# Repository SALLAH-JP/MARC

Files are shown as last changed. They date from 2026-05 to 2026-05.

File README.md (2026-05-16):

<div align="center">

MARC - Robot guide autonome

# 🤖 MARC

### *Mascareignes Assistant and Robot Compagnon*

**Robot mobile autonome, guide vocal du laboratoire de robotique de l'Université des Mascareignes.**








[**🎥 Voir la démo**](#-démonstration) · [**🚀 Installation**](#-installation) · [**📖 Documentation**](#-documentation)

</div>

---

## 📺 Démonstration

> 🎬 **[▶️ Cliquez ici pour voir MARC en action sur YouTube](https://youtu.be/REMPLACER_PAR_LIEN_YOUTUBE)**

MARC Demo (https://youtu.be/REMPLACER_PAR_LIEN_YOUTUBE)

*MARC navigue entre les stations du laboratoire, présente les robots et interagit vocalement.*

---

## 📋 Sommaire

- [À propos](#-à-propos)
- [Aperçu](#-aperçu)
- [Architecture](#%EF%B8%8F-architecture)
- [Matériel](#-matériel)
- [Structure du dépôt](#-structure-du-dépôt)
- [Installation](#-installation)
- [Utilisation](#-utilisation)
- [Architecture logicielle](#-architecture-logicielle)
- [Documentation](#-documentation)
- [Auteur](#-auteur)

---

## 🎯 À propos

MARC est un **projet de fin d'études** développé en 3ème année d'Informatique Appliquée à l'**Université des Mascareignes** (Maurice), en partenariat avec l'**Université de Limoges**.

L'objectif : créer un robot guide capable de **se déplacer de manière autonome** entre 7 stations du laboratoire de robotique, de **dialoguer en langage naturel** grâce à un Grand Modèle de Langage, et d'**exprimer des émotions** via une matrice LED. Le tout supervisé depuis une interface web temps réel.

Le robot est entièrement conçu à partir de zéro : **modélisation 3D sur Onshape**, **impression 3D**, **électronique custom**, **firmware embarqué** et **stack logiciel complet**.

---

## ✨ Aperçu

- 🧭 **Navigation autonome** par suivi de ligne (3 capteurs IR) entre 7 stations
- 🎙️ **Pipeline vocal complet** : Speech-to-Text → LLM cloud (Mistral via Ollama) → Text-to-Speech
- 🧠 **Sortie JSON structurée** : le LLM génère directement des commandes exécutables
- 🌐 **Interface web HTTPS temps réel** : parcours SVG, journal d'événements, Push-To-Talk, mises à jour SSE
- 👀 **Matrice LED RGB 64×32** avec 6 expressions GIF (neutre, clignement, suspicieux, disparition, larme, amour)
- ⚖️ **Tentative auto-équilibrante PID** documentée et analysée *(mode finalement abandonné pour la navigation, voir le rapport)*

<div align="center">
Matrice LED RGB de MARC
<br/>
<i>La matrice LED RGB 64×32 pendant les tests d'animation</i>
</div>

---

## 🏗️ Architecture

Le système est distribué en trois couches :

```
┌─────────────────────────────────────────────┐
│  Couche matérielle                          │
│  Arduino Mega 2560 — 16 MHz, PID 100 Hz     │
│  Moteurs NEMA 23 · TB6600 · IR · BNO085     │
└──────────────────┬──────────────────────────┘
                   │ UART 115 200 bauds
                   │ (/dev/ttyACM0)
┌──────────────────┴──────────────────────────┐
│  Couche applicative                         │
│  Raspberry Pi 4 Model B — 1 Go RAM          │
│  Flask HTTPS + SSE · pipeline vocal · LED   │
└──────────────────┬──────────────────────────┘
                   │ HTTPS — API Ollama
┌──────────────────┴──────────────────────────┐
│  Intelligence distante                      │
│  Mistral Large via Ollama Cloud             │
│  Sortie JSON structurée                     │
└─────────────────────────────────────────────┘
```

---

## 🔧 Matériel

<div align="center">
Plateforme matérielle de MARC
<br/>
<i>Vue rapprochée du châssis : moteurs NEMA 23, drivers TB6600 et électronique de commande</i>
</div>

| Composant | Référence |
| --- | --- |
| Microcontrôleur | Arduino Mega 2560 |
| Ordinateur de bord | Raspberry Pi 4 Model B (1 Go RAM) |
| Moteurs | Pas-à-pas NEMA 23 ×2 |
| Drivers moteurs | TB6600 ×2 |
| Centrale inertielle | BNO085 (SPI, CS pin 47) |
| Capteurs ligne | 3 capteurs IR — pins 49 (G), 40 (C), 48 (D) |
| Affichage | Matrice LED RGB 64×32 (HUB75) |
| Télécommande | Récepteur IR (pin 46) — réglage PID, manuel |

> 💡 La modélisation 3D complète a été réalisée sur **Onshape** et le robot a été imprimé en 3D au laboratoire de l'UDM.

---

## 🧱 Conception 3D

L'intégralité de la mécanique de MARC a été **modélisée sur Onshape** puis **imprimée en 3D** au laboratoire de l'UDM. Le robot se décompose en **3 sous-ensembles** : la coque externe esthétique, la structure interne porteuse, et la tête (matrice LED).

<div align="center">
Modélisation Onshape de MARC
<br/>
<i>Modèle 3D complet de MARC sur Onshape</i>
</div>

### 🔗 Visualisation interactive

👉 **[Voir le modèle 3D complet sur Onshape](https://cad.onshape.com/documents/bc8d4e2fc1fa99c54b0ae445/w/f22cc56c4e97ab29b572a8dc/e/e2a230c46f8ff9770799be93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)**

### 📦 Fichiers 3D disponibles

Tous les fichiers source sont dans [`hardware/3d-models/`](assets/3d-models/), au format **STL** (impression directe) et **STEP** (édition CAO).

> 💡 Astuce : cliquez sur n'importe quel fichier `.stl` directement sur GitHub pour le **visualiser en 3D** dans votre navigateur.

#### 🏛️ Coque externe

Habillage esthétique du robot, imprimé en plusieurs morceaux pour respecter les contraintes du plateau d'impression.

| Pièce | STL | STEP |
|---|-----|---|
| Colonne V3 | [STL](assets/3d-models/ColonneV3.stl) | [STEP](assets/3d-models/ColonneV3.step) |
| Corps Bas — Avant | [STL](assets/3d-models/CorpsBasAvant.stl) | [STEP](assets/3d-models/CorpsBasAvant.step) |
| Corps Bas — Arrière | [STL](assets/3d-models/CorpsBasArriere.stl) | [STEP](assets/3d-models/CorpsBasArriere.step) |
| Corps Haut — Avant | [STL](assets/3d-models/CorpsHautAvant.stl) | [STEP](assets/3d-models/CorpsHautAvant.step) |
| Corps Haut — Arrière | [STL](assets/3d-models/CorpsHautArriere.stl) | [STEP](assets/3d-models/CorpsHautArriere.step) |
| Étage 0 (base) | [STL](assets/3d-models/Etage0.stl) | [STEP](assets/3d-models/Etage0.step) |
| Porte d'accès | [STL](assets/3d-models/Porte.stl) | [STEP](assets/3d-models/Porte.step) |
| Support capteurs IR | [STL](assets/3d-models/SupportTrackingSensor.stl) | [STEP](assets/3d-models/SupportTrackingSensor.step) |

#### 🦴 Structure interne

Squelette porteur qui supporte l'électronique, les moteurs et les batteries.

| Pièce | STL | STEP |
|---|-----|---|
| Colonne V1 | [STL](assets/3d-models/ColonneV1.stl) | [STEP](assets/3d-models/ColonneV1.step) |
| Coque interne | [STL](assets/3d-models/Coque.stl) | [STEP](assets/3d-models/Coque.step) |
| Étage 1 | [STL](assets/3d-models/Etage1.stl) | [STEP](assets/3d-models/Etage1.step) |
| Étage 2 | [STL](assets/3d-models/Etage2.stl) | [STEP](assets/3d-models/Etage2.step) |
| Étage 3 | [STL](assets/3d-models/Etage3.stl) | [STEP](assets/3d-models/Etage3.step) |
| Bague de réduction | [STL](assets/3d-models/BagueDeReduction.stl) | [STEP](assets/3d-models/BagueDeReduction.step) |
| Roue | [STL](assets/3d-models/Roue.stl) | [STEP](assets/3d-models/Roue.step) |
| Part 8 | [STL](assets/3d-models/Part8.stl) | [STEP](assets/3d-models/Part8.step) |

#### 🤖 Tête

Module supérieur portant la matrice LED 64×32 (le « visage » de MARC).

| Pièce | STL | STEP |
|---|-----|---|
| Tête — partie basse | [STL](assets/3d-models/TeteBas.stl) | [STEP](assets/3d-models/TeteBas.step) |
| Tête — partie haute | [STL](assets/3d-models/Tete-Haut.stl) | [STEP](assets/3d-models/TeteHaut.step) |
| Cadre matrice LED | [STL](assets/3d-models/tete/Matrice-Led.stl) | [STEP](assets/3d-models/MatriceLed.step) |

---

## 📁 Structure du dépôt

```
.
├── ControlMoteur/                 # Code embarqué Arduino Mega
│   ├── ControlMoteur.ino          # Boucle principale : PID, suivi de ligne, série
│   ├── header.h                   # Définitions broches, constantes, objets PID
│   └── fonctions.ino              # Fonctions auxiliaires (setMotors, lineTracking…)
│
├── Local-Voice/                   # Pipeline vocal Python (fork m15-ai/Local-Voice)
│   ├── voiceAssistant.py          # STT (Google) → LLM (Ollama cloud) → TTS (Edge)
│   ├── modelfile.txt              # Prompt système + base de connaissances
│   ├── requirements.txt
│   └── piper/                     # (optionnel) binaire Piper + voix offline
│
├── matrixLed/                     # Pilotage de la matrice LED RGB 64×32
│   ├── eye_manager.py             # Gestion thread-safe des animations + clignement
│   ├── gif_viewer.py              # Lecteur GIF simple (test standalone)
│   ├── SplitEyes.py               # Génération des GIFs depuis une vidéo source
│   ├── style1/                    # Set d'expressions style 1 (6 GIF)
│   └── style2/                    # Set d'expressions style 2 (6 GIF)
│
├── web/                           # Serveur Flask + interface web
│   ├── server.py                  # Flask HTTPS + SSE + worker série
│   ├── index.html                 # Application monopage HTML/CSS/JS
│   ├── style.css                  # Styles (parcours SVG, journal, Push-To-Talk)
│   ├── cert.pem / key.pem         # Certificat SSL auto-signé (à générer)
│   └── ...
│
├── docs/
│   ├── images/                    # Photos et captures du projet
│   └── Rapport_PFE_MARC.pdf       # Rapport complet du projet
│
└── .gitignore
```

---

## 🚀 Installation

### Prérequis

- Raspberry Pi 4 (Raspberry Pi OS 64 bits recommandé)
- Arduino Mega 2560 + IDE Arduino
- Python 3.9 ou supérieur
- Compte [Ollama](https://ollama.com) avec accès à l'API cloud (clé API)
- Réseau Wi-Fi local
- `ffmpeg`, `mpg123`, `sox`, `alsa-utils` installés sur le Pi

### Côté Arduino

1. Ouvrir `ControlMoteur/ControlMoteur.ino` dans l'IDE Arduino.
2. Installer via le gestionnaire de bibliothèques :
   - [`FastAccelStepper`](https://github.com/gin66/FastAccelStepper)
   - [`IRremote`](https://github.com/Arduino-IRremote/Arduino-IRremote)
   - [`SparkFun BNO08x Arduino Library`](https://github.com/sparkfun/SparkFun_BNO08x_Arduino_Library)
   - `PID_v1` (Brett Beauregard)
3. Vérifier les broches dans `header.h` (STEP/DIR/ENABLE moteurs, capteurs IR, BNO085, télécommande IR).
4. Compiler et téléverser sur l'Arduino Mega.

### Côté Raspberry Pi

```bash
# Cloner le dépôt
git clone https://github.com/SALLAH-JP/MARC.git
cd MARC

# Environnement Python
python3 -m venv env
source env/bin/activate
pip install -r Local-Voice/requirements.txt
pip install flask pyserial speechrecognition edge-tts pydub pillow

# Bibliothèque matrice LED (compilation native, requiert sudo plus tard)
git clone https://github.com/hzeller/rpi-rgb-led-matrix
cd rpi-rgb-led-matrix && make build-python PYTHON=$(which python3) && cd ..

# Dépendances système
sudo apt install ffmpeg mpg123 sox alsa-utils portaudio19-dev

# Certificat SSL auto-signé (HTTPS obligatoire pour le micro côté navigateur)
cd web
openssl req -x509 -newkey rsa:4096 -keyout key.pem -out cert.pem -days 365 -nodes
cd ..

# Variables d'environnement Ollama
export OLLAMA_API_KEY="<votre_clé>"
export OLLAMA_HOST="https://ollama.com"
```

### Lancement

```bash
# Terminal 1 — serveur web (HTTPS, port 5000) + matrice LED
cd web
sudo -E python3 server.py

# Terminal 2 — assistant vocal (wake word + commande)
cd Local-Voice
python3 voiceAssistant.py
```

L'interface web est accessible sur `https://<ip-du-pi>:5000` depuis n'importe quel appareil du réseau local. Le navigateur affichera un avertissement de sécurité dû au certificat auto-signé — c'est normal sur un réseau local, accepter l'exception.

> ⚠️ **Note** : `sudo` est nécessaire pour `server.py` car la bibliothèque `rpi-rgb-led-matrix` requiert un accès direct aux GPIO. Le drapeau `-E` préserve les variables d'environnement.

---

## 🎮 Utilisation

### Commande vocale

1. Dire le mot de réveil : *« Salut Marc »*.
2. Énoncer la commande, par exemple :
   - *« Va voir Pepper »* → navigation autonome jusqu'à la station Pepper
   - *« Présente-moi NAO »* → MARC s'y rend et donne une présentation
   - *« Reviens à la base »* → retour station 0
   - *« Change tes yeux »* → bascule entre style 1 et 2
3. MARC interprète la requête, confirme oralement et exécute.

### Interface web

- Cliquer sur une station du parcours SVG pour y envoyer le robot
- Activer ou désactiver le mode guide
- Push-To-Talk pour enregistrer une commande vocale depuis le navigateur
- Suivre le journal des événements en temps réel (SSE — pas de rechargement)

### Stations disponibles

| ID web | Numéro physique | Équipement |
| --- | --- | --- |
| base | 0 | Point de départ |
| nao | 1 | Robot humanoïde NAO |
| vector | 2 | Robot mobile Vector |
| pepper | 3 | Robot humanoïde Pepper |
| imp3d | 4 | Imprimante 3D Zortrax |
| baxter | 5 | Robot industriel Baxter |
| bras | 6 | Bras Franka Panda |

---

## 🧩 Architecture logicielle

**`ControlMoteur/`** — boucle Arduino à 200–500 Hz qui lit l'IMU, interprète les trames série venant du Pi (`C:move:turn` et `M:0/1`), exécute soit le suivi de ligne soit la télécommande IR, calcule les deux PID (équilibre + vitesse) et envoie les pas aux moteurs via FastAccelStepper. Quand une nouvelle station est détectée, l'Arduino renvoie `S:N` au Pi.

**`web/server.py`** — serveur Flask HTTPS qui héberge l'interface, expose les routes `/command`, `/vocal_command`, `/transcribe`, `/status`, `/line_following`, et un flux SSE `/events` pour les mises à jour temps réel vers le navigateur. Un thread daemon tourne en parallèle pour la communication série.

**`Local-Voice/voiceAssistant.py`** — pipeline vocal indépendant : écoute permanente du wake word via SpeechRecognition (Google STT), interprétation par Mistral Large via l'API Ollama cloud avec sortie JSON contrainte, synthèse vocale française avec `edge-tts` (voix `fr-FR-HenriNeural`), envoi de la commande au serveur Flask via HTTPS POST.

**`matrixLed/eye_manager.py`** — gestionnaire thread-safe de la matrice LED, clignement aléatoire en arrière-plan (3 à 7 secondes), interruption immédiate pour jouer une animation à la demande, rechargement à chaud lors d'un changement de style.

---

## 📖 Documentation

Le rapport complet de Projet de Fin d'Études détaille :
- l'analyse des besoins
- les choix d'architecture
- l'analyse du conflit PID-équilibre vs suivi de ligne
- les tests d'une vingtaine de modèles LLM réalisés sur Raspberry Pi 4
- la modélisation 3D sur Onshape
- les résultats expérimentaux

📄 Disponible dans [`docs/Rapport_PFE_MARC.pdf`](docs/Rapport_PFE_MARC.pdf).

---

## 👤 Auteur

**SALLAH Assiongbon Théodore Jean-Paul**
Étudiant en 3ème année — Informatique Appliquée
🎓 Université des Mascareignes · Université de Limoges
📅 Année universitaire 2024 / 2025

**Encadrant pédagogique :** M. Khadimoullah Ramoth



---

## 🙏 Remerciements

Ce projet doit beaucoup à plusieurs contributions extérieures :

- Le projet [Local-Voice](https://github.com/m15-ai/Local-Voice) de M15.ai, dont l'architecture a inspiré le pipeline vocal
- La plateforme [Ollama](https://ollama.com) et le modèle Mistral Large
- La bibliothèque [FastAccelStepper](https://github.com/gin66/FastAccelStepper) de J. Kerschbaumer
- La bibliothèque [rpi-rgb-led-matrix](https://github.com/hzeller/rpi-rgb-led-matrix) de H. Zeller
- [edge-tts](https://github.com/rany2/edge-tts), [Flask](https://flask.palletsprojects.com), [SpeechRecognition](https://github.com/Uberi/speech_recognition)
- Les fournisseurs locaux Advanced Electronique et Transcom (Maurice)

---

## 📜 Licence

Ce projet est distribué sous licence **MIT** — voir le fichier [`LICENSE`](LICENSE).

Le code des bibliothèques tierces utilisées reste sous leurs licences respectives.

---

<div align="center">

*Si ce projet vous a plu, n'hésitez pas à laisser une ⭐ !*

</div>

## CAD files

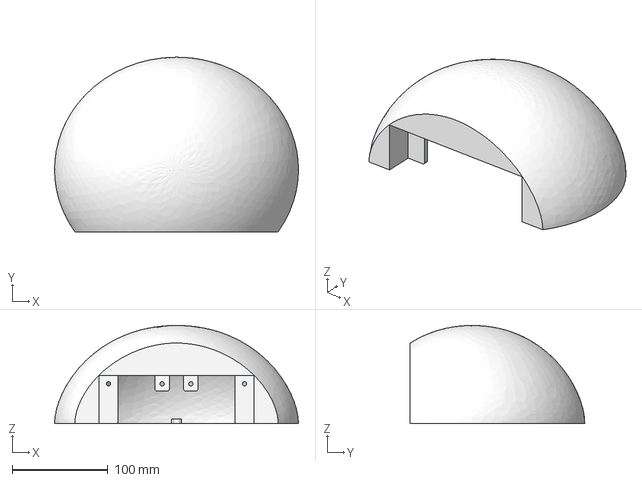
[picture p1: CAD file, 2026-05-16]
assets/3d-models/TeteHaut.step
255.0 x 182.5 x 102.5 mm

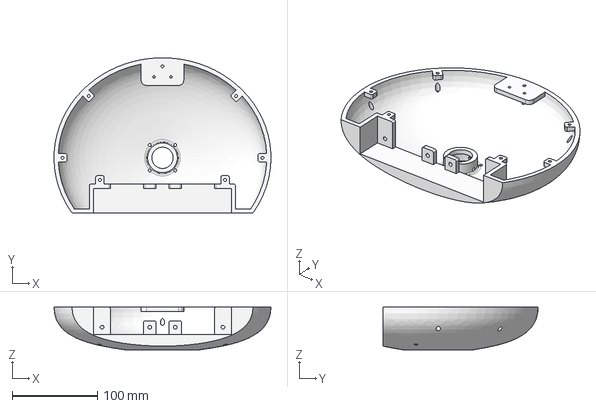
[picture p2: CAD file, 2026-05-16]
assets/3d-models/TeteBas.step
255.0 x 182.4 x 50.0 mm

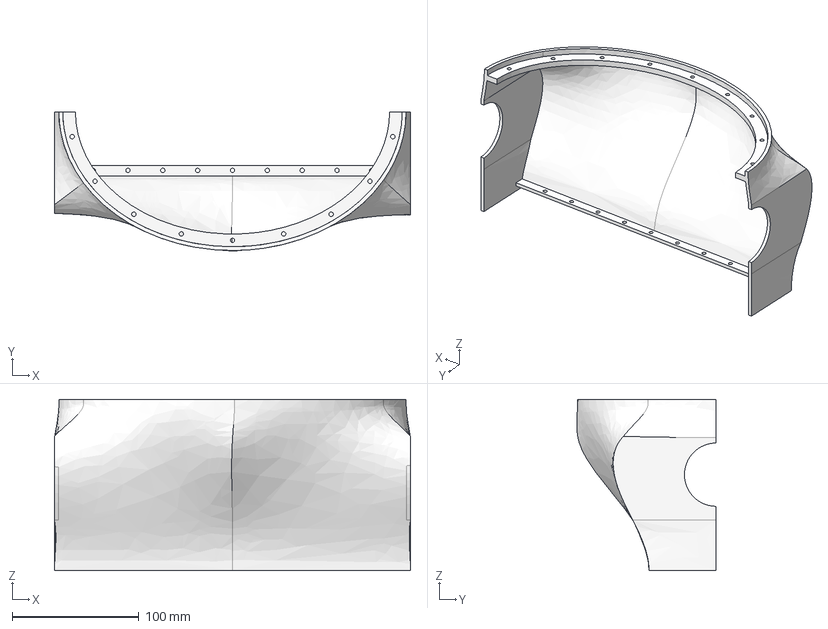
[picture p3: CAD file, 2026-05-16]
assets/3d-models/CorpsBasAvant.step
281.0 x 110.0 x 135.0 mm

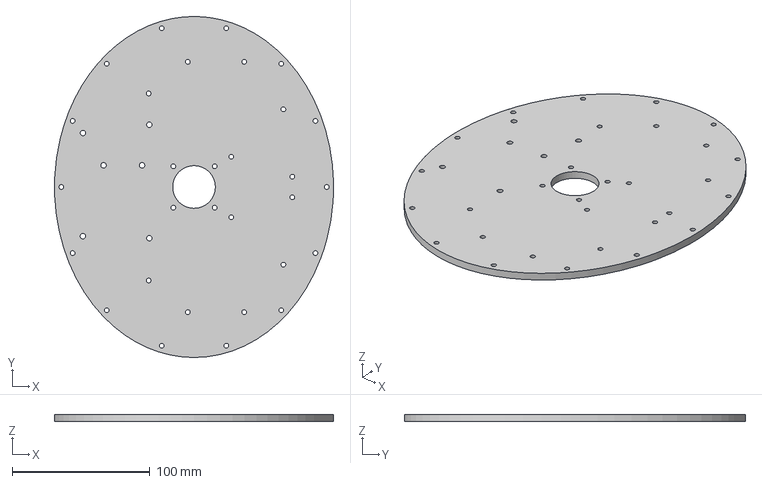
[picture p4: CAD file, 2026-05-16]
assets/3d-models/Etage2.step
203.0 x 248.0 x 5.00 mm

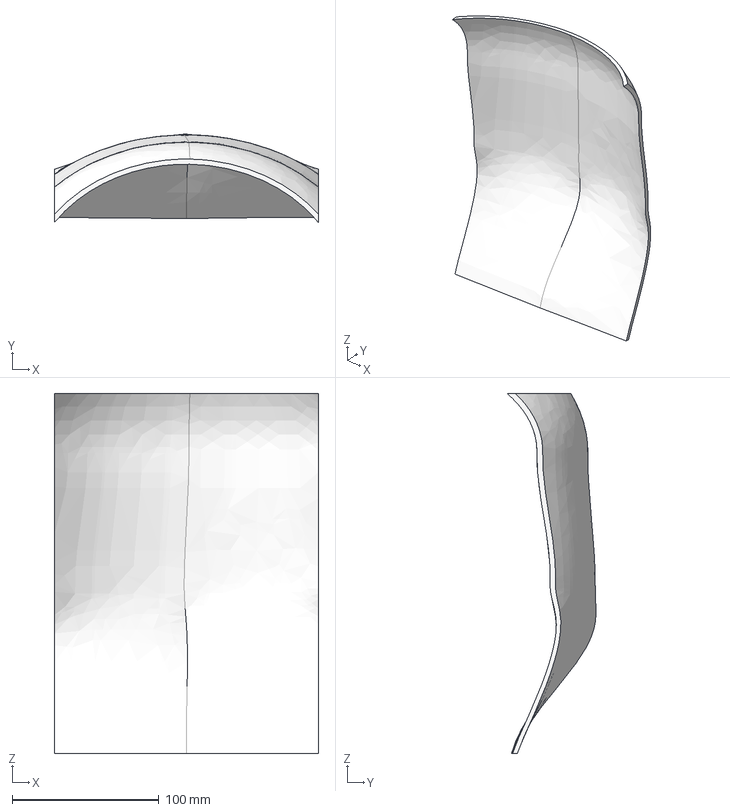
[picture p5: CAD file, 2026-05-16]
assets/3d-models/Porte.step
180.0 x 60.5 x 245.0 mm

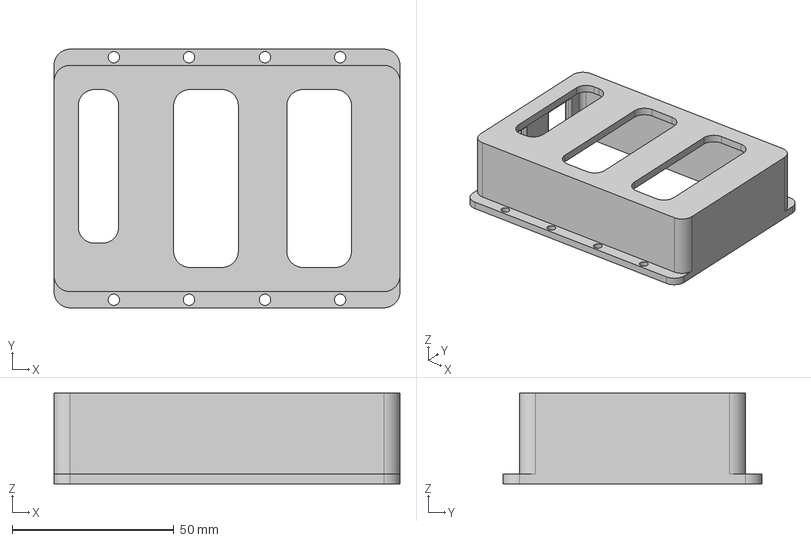
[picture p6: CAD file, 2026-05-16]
assets/3d-models/Coque.step
107.0 x 80.0 x 28.0 mm

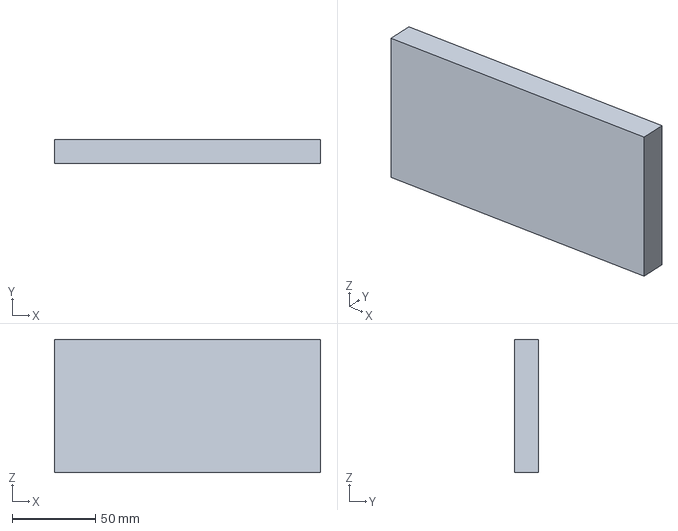
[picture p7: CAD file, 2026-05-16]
assets/3d-models/MatriceLed.step
160.0 x 14.5 x 80.0 mm

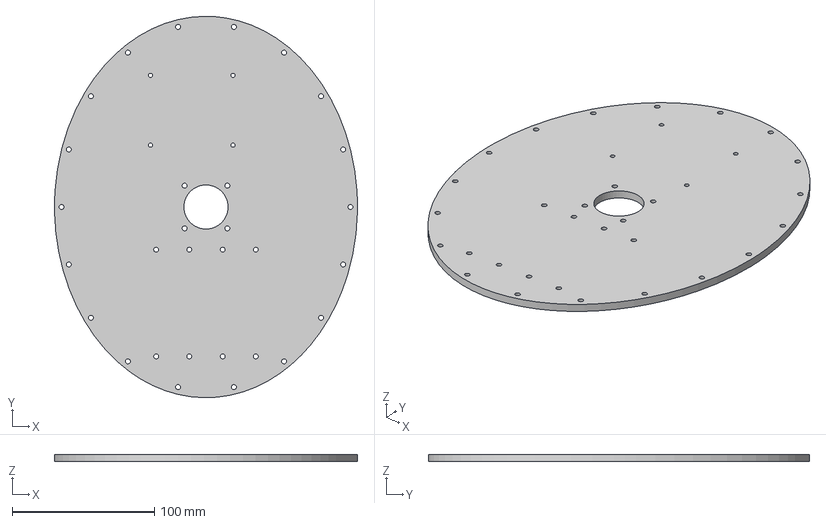
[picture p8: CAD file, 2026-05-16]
assets/3d-models/Etage3.step
212.9 x 268.0 x 5.00 mm

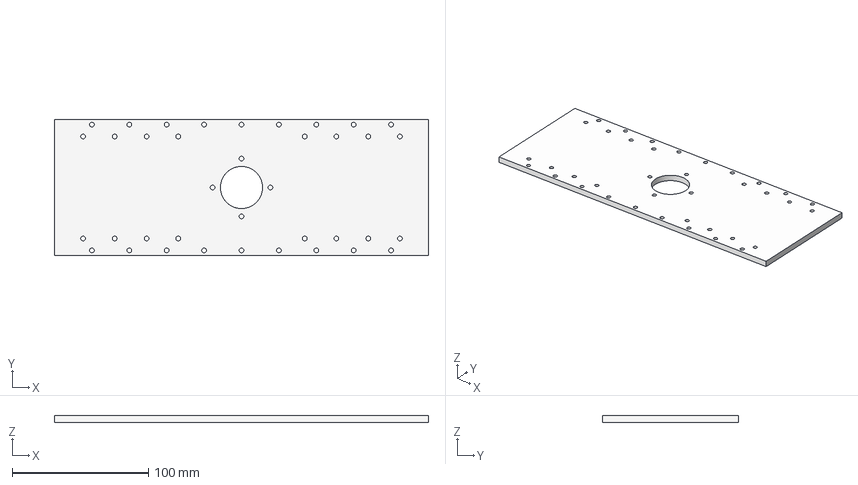
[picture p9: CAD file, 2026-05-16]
assets/3d-models/Etage0.step
275.0 x 100.0 x 5.00 mm

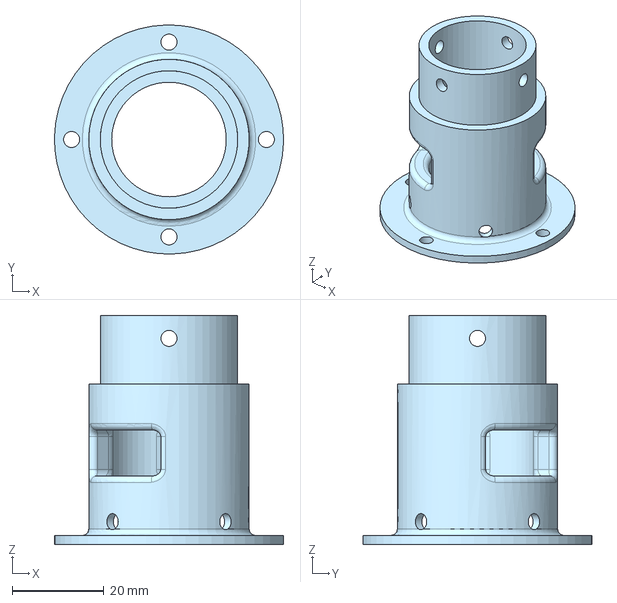
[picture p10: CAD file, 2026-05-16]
assets/3d-models/ColonneV3.step
50.0 x 50.0 x 50.0 mm

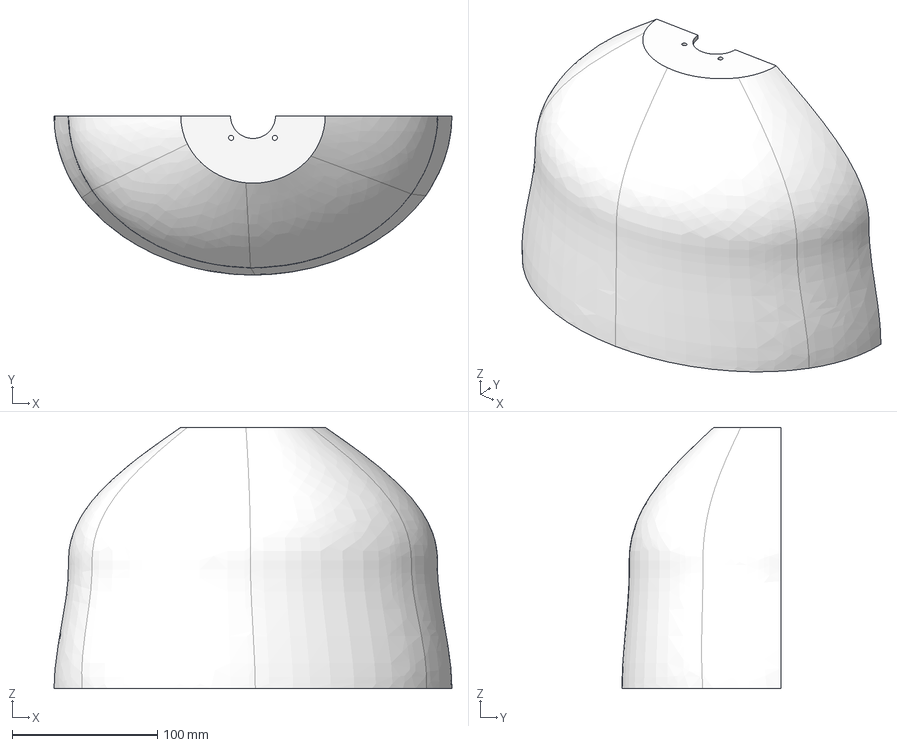
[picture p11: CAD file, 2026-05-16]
assets/3d-models/CorpsHautAvant.step
274.0 x 109.5 x 180.0 mm

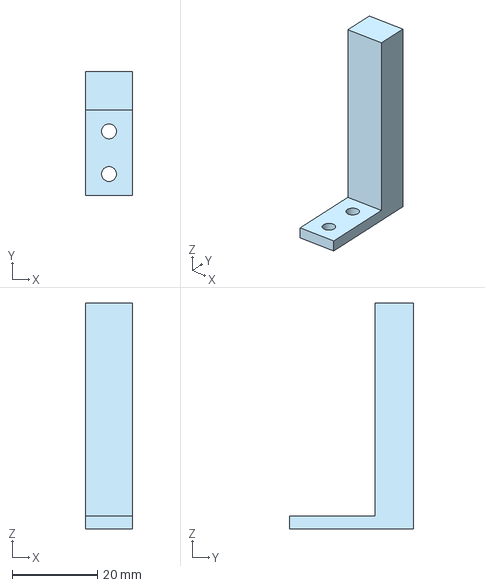
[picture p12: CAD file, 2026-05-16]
assets/3d-models/Part8.step
11.0 x 29.0 x 53.0 mm

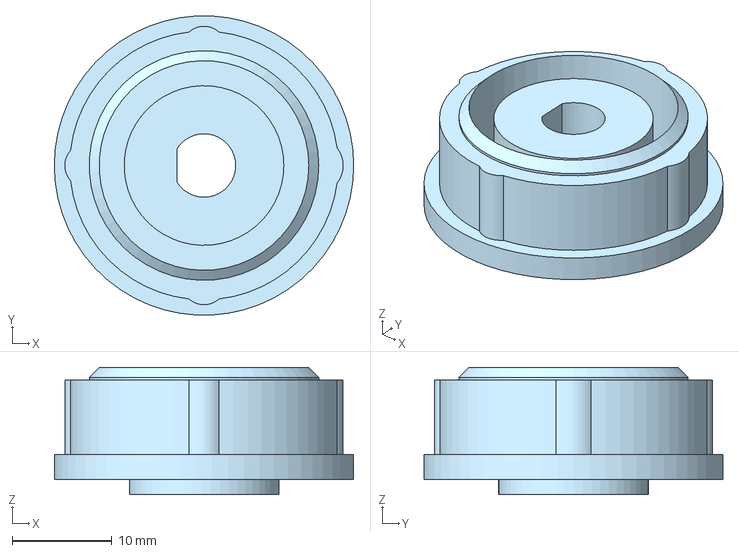
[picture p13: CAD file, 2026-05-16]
assets/3d-models/BagueDeReduction.step
30.0 x 30.0 x 12.8 mm

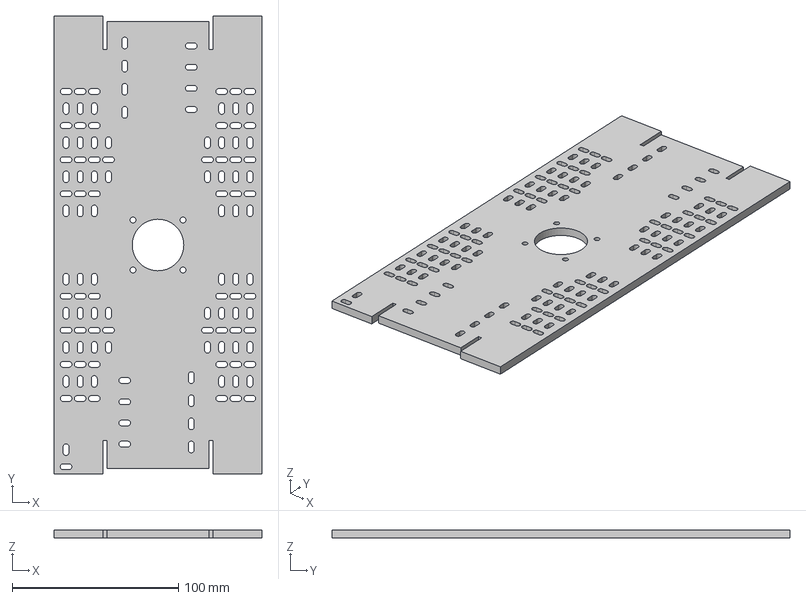
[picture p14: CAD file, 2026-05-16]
assets/3d-models/Etage1.step
125.0 x 275.0 x 5.00 mm

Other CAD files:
assets/3d-models/SupportTrackingSensor.step
assets/3d-models/CorpsBasArriere.step
assets/3d-models/CorpsHautArriere.step
assets/3d-models/Roue.step
assets/3d-models/BagueDeReduction.stl
assets/3d-models/ColonneV1.step
assets/3d-models/Coque.stl
assets/3d-models/CorpsBasArriere.stl
assets/3d-models/CorpsBasAvant.stl
assets/3d-models/CorpsHautArriere.stl
assets/3d-models/CorpsHautAvant.stl
assets/3d-models/Etage0.stl
assets/3d-models/Etage1.stl
assets/3d-models/Etage2.stl
assets/3d-models/Etage3.stl
assets/3d-models/MatriceLed.stl
assets/3d-models/Part8.stl
assets/3d-models/Porte.stl
assets/3d-models/Roue.stl
assets/3d-models/SupportTrackingSensor.stl
assets/3d-models/TeteBas.stl
assets/3d-models/TeteHaut.stl

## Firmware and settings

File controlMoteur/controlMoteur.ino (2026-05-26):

#include "header.h"


void setup() {
  Serial.begin(115200);

  Serial.println("Start Setup");


  //if (myIMU.begin() == false) {  // Setup without INT/RST control (Not Recommended)
  while (imu.beginSPI(BNO08X_CS, BNO08X_INT, BNO08X_RST) == false) {
    Serial.println("BNO08x not detected at default I2C address. Check your jumpers and the hookup guide. Freezing...");
    delay(100);
  }
  Serial.println("BNO08x found!");


  delay(100);
  setReports();
  Serial.println("Reading events");
  delay(100);

  // IR Receiver Setup and interrupt
  IrReceiver.begin(IR_PIN, ENABLE_LED_FEEDBACK);


  // Activer les moteurs
  engine.init();

  // Moteur droit
  motorR = engine.stepperConnectToPin(STEP_PIN_R);   // STEP droit
  if (motorR) {
    motorR->setDirectionPin(DIR_PIN_R);            // DIR droit
    motorR->setEnablePin(ENA_PIN_R, false);               // EN droit
    motorR->setAutoEnable(true);
    motorR->setAcceleration(3000);
  }

  // Moteur gauche
  motorL = engine.stepperConnectToPin(STEP_PIN_L);   // STEP gauche
  if (motorL) {
    motorL->setDirectionPin(DIR_PIN_L);            // DIR gauche
    motorL->setEnablePin(ENA_PIN_L, false);               // EN gauche
    motorL->setAutoEnable(true);
    motorL->setAcceleration(3000);
  }


  // Tracking Sensor Setup
  pinMode(LEFT_SENSOR_PIN, INPUT);
  pinMode(RIGHT_SENSOR_PIN, INPUT);
  pinMode(CENTER_SENSOR_PIN, INPUT);

  setupUltrasons();

  // PID
  pidA.SetSampleTime(10);
  pidA.SetOutputLimits(-5000, 5000);
  pidA.SetMode(AUTOMATIC);

  pidV.SetSampleTime(10);
  pidV.SetOutputLimits(-45, 45);
  pidV.SetMode(AUTOMATIC);


  Serial.println("Setup Completed !");
}


void loop() {

  if (imu.wasReset()) {
    Serial.print("sensor was reset ");
    setReports();
  }

  moveCmd = 0;
  turnCmd = 0;

  readSerialCommand();


  if (lineFollowingMode) {
    lineTracking();        // suit la ligne, ignore la télécommande
  } else {
    remoteControl();       // télécommande active, pas de suivi
  }

  // filtrage passe-bas des commandes
  currentMoveCmd = moveCmd; //lowPassFilter(moveCmd, currentMoveCmd, 0.8);
  currentTurnCmd = turnCmd; //lowPassFilter(turnCmd, currentTurnCmd, 0.8);

  inputV = measureSpeed();

  if ( imu.getSensorEvent() == true) {
    if ( imu.getSensorEventID() == SENSOR_REPORTID_ROTATION_VECTOR ) {
    
      inputA = (imu.getRoll()) * 180.0 / PI - 180;
      if ( inputA < -180) inputA += 360;

      // Envoi du yaw au Pi à 10 Hz (localisation)
      static unsigned long lastYawSend = 0;
      if (millis() - lastYawSend > 100) {
        float yaw = imu.getYaw() * 180.0 / PI;
        Serial.print("Y:");
        Serial.println(yaw, 1);
        lastYawSend = millis();
      }



      // Envoi de la distance parcourue au Pi à 10 Hz
      static unsigned long lastDistSend = 0;
      if (millis() - lastDistSend > 100) {
         long posL = motorL->getCurrentPosition();
         long posR = -motorR->getCurrentPosition();   // signe inversé comme dans measureSpeed
         // distance moyenne en cm
         float stepsToCm = (PI * WHEEL_DIAMETER) / (STEPS_REV * MICRO_STEPS);
         float distL = posL * stepsToCm;
         float distR = posR * stepsToCm;
         float dist = (distL + distR) / 2.0;
         Serial.print("D:");
         Serial.println(dist, 1);
         lastDistSend = millis();
      }

      updateUltrasons();
      sendUltrasons();

      pidV.Compute();
      setpointA = EQUILIBRE + outputV;
      pidA.Compute();
    
      //Serial.print(inputA); Serial.print(" => "); Serial.println(outputA);
      //Serial.print(inputV); Serial.print(" => "); Serial.println(outputV);
    }    

  }
  

  //Serial.print(KpA); Serial.print(" => "); Serial.print(KiA); Serial.print(" => "); Serial.println(KdA);
  //Serial.print(KpV); Serial.print(" => "); Serial.print(KiV); Serial.print(" => "); Serial.println(KdV);
  //Serial.println();
  //Serial.print(currentMoveCmd); Serial.print(" => "); Serial.println(currentTurnCmd);
  setMotors(currentMoveCmd, currentTurnCmd);
  //temps();

}

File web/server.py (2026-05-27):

#!/usr/bin/env python3
"""
MARC Robot — server.py
Serveur Flask : reçoit les commandes depuis voiceAssistant.py (HTTP)
et depuis l'interface web (boutons/clics).
"""

import os
import sys
import time
import tempfile
import threading
import json
import queue

from flask import Flask, request, jsonify, send_from_directory, Response

# ── Imports voiceAssistant (fonctions partagées) ──
ROOT = os.path.abspath(os.path.join(os.path.dirname(__file__), ".."))
sys.path.append(os.path.join(ROOT, "assistantVocale"))
sys.path.append(os.path.join(ROOT, "matrixLed"))
from voiceAssistant import speak, ask_ollama, recognizer

# ── Matrix LED (optionnel) ──
try:
    from rgbmatrix import RGBMatrix, RGBMatrixOptions
    from eye_manager import EyeManager
    MATRIX_AVAILABLE = True
except ImportError:
    print("⚠️  rgbmatrix non disponible (mode PC)")
    MATRIX_AVAILABLE = False


# ─────────────────────────────────────────────
#  SERIAL (Arduino)
# ─────────────────────────────────────────────
arduino      = None
ARDUINO_PORT = '/dev/ttyACM0'
ARDUINO_BAUD = 115200

try:
    import serial
    arduino = serial.Serial(ARDUINO_PORT, ARDUINO_BAUD, timeout=2)
    time.sleep(2)
    arduino.reset_input_buffer()
    SERIAL_AVAILABLE = True
    print(f'[Arduino] Connecté sur {ARDUINO_PORT} ✓')
except Exception as e:
    print(f'[Arduino] Non connecté (ignoré) : {e}')
    SERIAL_AVAILABLE = False
    arduino = None


from collections import deque
import statistics

_us_gauche_buf = deque(maxlen=10)
_us_droite_buf = deque(maxlen=10)

# ─────────────────────────────────────────────
#  CONFIGURATION
# ─────────────────────────────────────────────
GIF_DIR  = os.path.join(ROOT, "matrixLed")


# ─────────────────────────────────────────────
#  ÉTAT GLOBAL
# ─────────────────────────────────────────────
robot_state = {
    "current": "base",
    "target":  None,
    "eyes":    1,
    "mode":    "idle",
}

current_move      = 0
current_turn      = 0
station_actuelle  = -1
destination_cible = None
line_following    = False
eyes = None
robot_yaw         = 0.0   # cap brut du BNO085 (degrés)
robot_distance    = 0.0   # distance cumulée parcourue (cm)
us_centre = -1.0
us_gauche = -1.0
us_droite = -1.0


# Numéro de station physique → id web
STATION_NUMBERS = {
    "base":   0,
    "nao":    1,
    "vector": 2,
    "pepper": 3,
    "imp3d":  4,
    "baxter": 5,
    "bras":   6,
}

# Numéro physique → id web (inverse)
STATION_BY_NUMBER = {v: k for k, v in STATION_NUMBERS.items()}

# Nom LLM → id web
DESTINATION_MAP = {
    "Nao":           "nao",
    "Vector":        "vector",
    "Pepper":        "pepper",
    "Imprimante3D":  "imp3d",
    "Baxter":        "baxter",
    "brasRobotique": "bras",
    "Base":          "base",
}


# ─────────────────────────────────────────────
#  HELPERS ÉTAT
# ─────────────────────────────────────────────
def full_state() -> dict:
    """Retourne robot_state enrichi avec line_following."""
    return {**robot_state, "line_following": line_following}


# ─────────────────────────────────────────────
#  SSE — Server-Sent Events (temps réel vers le navigateur)
# ─────────────────────────────────────────────
# Chaque navigateur connecté possède sa propre file. Quand on appelle
# broadcast(...), l'événement est posté dans toutes les files. Le générateur
# attaché à /events vide la file et l'écrit dans le flux HTTP du client.
sse_clients: list[queue.Queue] = []
sse_lock = threading.Lock()


def _sse_format(event: str, data: dict) -> str:
    """Formate un message SSE conforme au protocole."""
    return f"event: {event}\ndata: {json.dumps(data, ensure_ascii=False)}\n\n"


def broadcast(event: str, data: dict) -> None:
    """Envoie un événement à tous les navigateurs connectés."""
    msg = _sse_format(event, data)
    with sse_lock:
        dead = []
        for q in sse_clients:
            try:
                q.put_nowait(msg)
            except queue.Full:
                dead.append(q)
        for q in dead:
            sse_clients.remove(q)


def broadcast_state() -> None:
    """Pousse l'état complet du robot à tous les clients."""
    broadcast("state", full_state())


def broadcast_speech(text: str) -> None:
    """Pousse une phrase prononcée par MARC à tous les clients."""
    broadcast("speech", {"text": text})


def broadcast_log(message: str, level: str = "info") -> None:
    """Pousse une entrée de journal à tous les clients."""
    broadcast("log", {"message": message, "level": level})


# ─────────────────────────────────────────────
#  MATRIX LED
# ─────────────────────────────────────────────
matrix = None
if MATRIX_AVAILABLE:
    options = RGBMatrixOptions()
    options.rows = 32
    options.cols = 64
    options.led_rgb_sequence = "RBG"
    options.brightness = 75
    options.disable_hardware_pulsing = True
    options.hardware_mapping = "regular"
    matrix = RGBMatrix(options=options)

    eyes = EyeManager(matrix, GIF_DIR, style=2)
    eyes.start()
    print("✅  Matrix LED initialisée")


def clear_matrix():
    if MATRIX_AVAILABLE and matrix:
        matrix.Clear()
        if eyes: eyes.stop()
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

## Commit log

2026-05-16 reorganisation du readme + ajout des modele 3D
    [BagueDeReduction.step, BagueDeReduction.stl, ColonneV1.step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]
2026-05-19 Premier pas de la camera
2026-05-21 modif ver la navigation autonome
2026-05-23 Amelioration de la navigation, Localisation par Aruco + Odométrie
2026-05-25 Localisation + destination vers la cible fonctionnnelle avec ARUCO + Odométrie
2026-05-26 Logique evitemment des obstacles

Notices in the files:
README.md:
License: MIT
